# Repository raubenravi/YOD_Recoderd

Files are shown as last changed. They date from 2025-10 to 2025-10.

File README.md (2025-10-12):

# YOD Recorder - ESP32 Audio Recording System

ESP32-based audio recording system for research applications with QR code scanning and external hardware control.
This project contains the software developed for a graduation internship at the Hogeschool Utrecht research group artificial intelligence (lectoraat Ai).

# Developer Responsibility

** IMPORTANT NOTICE **

This system is designed for research and development purposes. **Before using this system in real-life applications, especially in medical or research environments, developers and users must:**

1. **Think Twice Before Implementation**: Carefully evaluate the appropriateness and safety of using this system in your specific use case
2. **Stakeholder Consultation**: Always discuss implementation plans with relevant stakeholders including:
   - Medical professionals (if used in healthcare)
   - Research supervisors and ethics committees
   - IT security teams
   - Legal and compliance departments
   - End users and participants
3. **Personal Responsibility**: The developer who is using it is solely responsible for:
   - Proper system validation and testing
   - Ensuring compliance with applicable regulations
   - Risk assessment and mitigation
   - Obtaining necessary approvals and certifications
   - Training users appropriately

**This code is provided as-is without warranty. Use at your own risk and responsibility.**

## What You Need

### Hardware
- **ESP32-WROOM-32D DevKit**
- USB cable
- SSD1306 OLED Display (128x64)
- DS3231 RTC Module
- M5Scanner (QR Code Scanner)
- Tascam DR-40X Digital Recorder
- 4x Push Buttons + 2x LEDs + Speaker

## Setup ESP-IDF

**Easiest way - VS Code Extension:**
1. Install [Visual Studio Code](https://code.visualstudio.com/)
2. Install [ESP-IDF Extension](https://marketplace.visualstudio.com/items?itemName=espressif.esp-idf-extension)
3. Follow setup wizard for ESP-IDF v5.0+

**Manual installation:**
- [Windows Setup Guide](https://docs.espressif.com/projects/esp-idf/en/latest/esp32/get-started/windows-setup.html)
- [macOS Setup Guide](https://docs.espressif.com/projects/esp-idf/en/latest/esp32/get-started/macos-setup.html)
- [Linux Setup Guide](https://docs.espressif.com/projects/esp-idf/en/latest/esp32/get-started/linux-macos-setup.html)

## Hardware Connections

Connect components to these ESP32 pins:

| Component | Pin | Notes |
|---|-----|---|
| **Display** | | |
| SSD1306 SCL | GPIO 21 | I2C Clock |
| SSD1306 SDA | GPIO 22 | I2C Data |
| **Buttons** | | |
| Research | GPIO 34 | |
| Select | GPIO 35 | |
| Stop | GPIO 32 | |
| Patient | GPIO 4 | External case |
| **Audio** | | |
| Modem | GPIO 25 | PWM Output |
| Speaker | GPIO 27 | PWM Output |
| **LEDs** | | |
| Status LED 1 | GPIO 2 | External case |
| Status LED 2 | GPIO 15 | External case |
| **Tascam** | | |
| RX | GPIO 16 | UART |
| TX | GPIO 17 | UART |

## Quick Start

### 1. Get the Code
```bash
git clone https://github.com/raubenravi/YOD_Recoderd
cd "YOD Recoder"
```

### 2. Setup Environment
**Windows PowerShell:**
```powershell
export IDF_PATH=~/esp/esp-idf
```

**Windows Command Prompt:**
```cmd
%IDF_PATH%\export.bat
```

### 3. Build and Flash
```bash
idf.py set-target esp32
idf.py build
idf.py -p COM3 flash
```
*Replace COM3 with your ESP32's port*

### 4. View Logs (Optional)
```bash
idf.py -p COM3 monitor
```

## How It Works

### Controls
- **Green Research Button**: Start research recording
- **Yellow Research Button**: pauze recording  
- **Red Research Button**: Stop all recording
- **Patient Button**: Patient pause (external case)

### Features
- Real-time display on OLED screen
- Audio analysis
- add marks with modem communication
- QR code scanning for participant ID
- Controls Tascam DR-40X recorder 
- Status LEDs and audio feedback

## Project Structure
```
YOD Recoder/
├── code_esp32/main/    # Main application code
├── components/         # Custom components  
├── test_code/               # Unit and integration tests
└── build/             # Generated files

```

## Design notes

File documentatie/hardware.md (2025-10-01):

# YOD Recorder Hardware Pin Configuration

This document describes the GPIO pin assignments and hardware connections for the YOD Recorder ESP32 project.

## GPIO Pin Assignment Table

| GPIO Pin | Hardware Component | Function | Direction | Notes |
|---|---|---|---|---|
| GPIO_2 | LED Controller | Status LED | Output | Controlled by GpioController, External case via cable |
| GPIO_4 | Button | Patient Button | Input | Pull-up enabled, Negative edge interrupt, External case via cable |
| GPIO_12  | Display | Reset Pin | Output | SSD1306 OLED Display Reset |
| GPIO_15  | LED Controller | Status LED | Output | Controlled by GpioController, External case via cable |
| GPIO_16  | UART2 | RX Pin | Input | Tascam DR-40X Communication (Inverted) |
| GPIO_17  | UART2 | TX Pin | Output | Tascam DR-40X Communication (Inverted) |
| GPIO_21  | I2C | SCL (Clock) | I/O | Display & RTC Communication |
| GPIO_22  | I2C | SDA (Data) | I/O | Display & RTC Communication |
| GPIO_25  | Audio Modem | PWM Output | Output | Audio FSK Modem (23kHz/21kHz) |
| GPIO_27  | Speaker | PWM Output | Output | Beeper/Speaker Control |
| GPIO_32  | Button | Stop Button | Input | Pull-up enabled, Positive edge interrupt |
| GPIO_34  | Button | Research Button | Input | Pull-up enabled, Positive edge interrupt |
| GPIO_35  | Button | Select Button | Input | Pull-up enabled, Positive edge interrupt |

## Hardware Components Details

### Display System
- **Component**: SSD1306 OLED Display (128x64)
- **Interface**: I2C
- **Pins**: 
  - SCL: GPIO_21
  - SDA: GPIO_22
- **Address**: Default I2C address (typically 0x3C)

### Real-Time Clock (RTC)
- **Component**: DS3231 RTC Module
- **Interface**: I2C (shared with display)
- **Pins**:
  - SCL: GPIO_21
  - SDA: GPIO_22

### QR Code Scanner
- **Component**: M5Scanner
- **Interface**: I2C (shared with display and RTC)
- **Pins**:
  - SCL: GPIO_21
  - SDA: GPIO_22

### Button Interface
All buttons are configured with:
- Internal pull-up resistors enabled
- Pull-down resistors disabled
- Individual interrupt handlers

| Button | GPIO | Interrupt Type | Observer ID |
|---|---|---|---|
| Research/Pause | GPIO_34 | Positive Edge | ResearchPause |
| Select/Start | GPIO_35 | Positive Edge | Start |
| Stop | GPIO_32 | Positive Edge | Stop |
| Patient/Pause | GPIO_4 | Negative Edge | PatientPause (External case via cable) |

### Audio System
#### Audio Modem
- **GPIO**: GPIO_25
- **Function**: FSK (Frequency Shift Keying) Modem
- **Frequencies**: 
  - High: 23,000 Hz
  - Low: 21,000 Hz
- **Implementation**: PWM-based signal generation

#### Speaker/Beeper
- **GPIO**: GPIO_27
- **Function**: Audio feedback and notifications
- **Implementation**: PWM-based tone generation

### Communication Interfaces
#### UART2 - Tascam DR-40X Control
- **Port**: UART_NUM_2
- **TX Pin**: GPIO_17
- **RX Pin**: GPIO_16
- **Configuration**:
  - Baud Rate: 9600
  - Data Bits: 8
  - Parity: Even
  - Stop Bits: 2
  - Flow Control: Disabled
  - Signal Inversion: Both TX and RX inverted

#### I2C Bus
- **Port**: I2C_NUM_0
- **SCL**: GPIO_21
- **SDA**: GPIO_22
- **Devices**: SSD1306 Display, DS3231 RTC, M5Scanner
- **Speed**: Standard 100kHz

### LED Status Indicators
- **GPIO_2**: Status LED (controlled by GpioController) - External case via cable
- **GPIO_15**: Status LED (controlled by GpioController) - External case via cable
- **Function**: Visual status indication for system states
- **Connection**: LEDs are mounted in external case and connected to ESP32 via cable

## Power and Ground Connections
- All components require 3.3V power supply
- Common ground connections for all components
- ESP32 DevKit provides regulated 3.3V output

## Pin Usage Summary
- **Total GPIO pins used**: 12 out of available ESP32 pins
- **Input pins**: 4 (buttons)
- **Output pins**: 6 (LEDs, PWM, Reset)
- **I/O pins**: 2 (I2C)
- **Communication pins**: 2 (UART)

## External Case Connections
Some components are mounted in an external case and connected to the main ESP32 board via cable:

- **Patient Button (GPIO_4)**: External momentary push button in case, connected via cable
- **Status LEDs (GPIO_2, GPIO_15)**: External indicator LEDs in case, connected via cable
- **Power (3.3V) and Ground**: The external case provides connections for 3.3V power and ground to supply the button.

## Notes
- All GPIO pins are configured with appropriate pull-up/pull-down resistors
- PWM channels use LEDC peripheral for audio generation
- UART signals are inverted for Tascam compatibility
- I2C bus is shared among multiple devices with different addresses
- Button debouncing is handled in software with interrupt-driven detection
- External case connections require proper cable management and strain relief

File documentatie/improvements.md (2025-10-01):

De volgende punten moeten bijgewerkt worden:
- Een RGB LED zodat elke gewenste kleur kan worden getoond
- De spraak-stilte ratio moet een hogere resolutie krijgen of fijner afgesteld kunnen worden zodat het beter is in het detecteren van stiltes
- Een standaard met formaat 5/8-27 threaded hole op de cases zodat verschillende richt- en shotgun microfoons aan het systeem bevestigd kunnen worden
- Betere uitlijning van de knoppen op de case voor de onderzoekers

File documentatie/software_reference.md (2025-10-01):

# Reference Manual
This manual is for software developers who want to understand the structure of the code. To read it properly, use a reader that supports Markdown.
# Task Handling

After all objects are constructed, the `startTasks()` function from the Task handler is called.

The TaskHandler controls all tasks using the ESP-IDF FreeRTOS framework.

There are two tasks running on the ESP: one task is responsible for general control of the system and its peripherals (`observerUpdateTask`).

## Observer Update Task
The `observerUpdateTask()` has 4 observers and one listener.
When the update function runs, the observers are stored in a vector because it's easier for development, but should be transferred to an array when memory becomes an issue or when it goes to production. When a new implementation of the observer is made, a new ID should be added to `ObserverIds`.

The observers are checked every 200 ms.

# Audio Analyser Task
The second task that is running is a task to count the silence-to-speaking ratio.
Every 250 ms, the audio analyser measures whether the speaker is silent or speaking.

# Observer-Listener Pattern

An example of how to make a new Observer:

```
//found in Observer.hpp
enum class ObserverIds {

    Start,

    Stop,

    PatientPause,

    ResearchPause,

    CodeScanner,

    AudioDataAvailable

/* add new id here */

};

class MyObserver: public Observer {

  ObserverId id;

  void update(){

  if() // Here should be the logic to check if Observer measured an event
  {
    listener->notify(id);
 }
};

};

```
There are two listeners: the menu controller and display controller.

# Button Handling

The buttons in the YOD recorder are polled with interrupt pins and integrated with the listener pattern. When a button is pressed, a flag will be set by the interrupt. When the `update()` function is called, the flag will be read and if necessary, it will call the `menuController.notify()` to update its state. 

# Menu Controller
The `MenuController` class contains most of the business logic. It contains an enum with the state of the recorder. The state can be changed by calling `notify()`. After `notify()` is called, the `menuTask` is called to update the state machine.

The `startRecording()` function is responsible for ensuring that the audio modem has the right data and that the right `TascamBoundary` is called.

The Tascam recorder used in the project (Tascam DR-40X) can be controlled with UART (see hardware documentation for how to connect it).
The Tascam has 3 states: stop, idle, and recording.
The `TascamBoundary` class can control and set the recorder to any of the 3 states independently of the current state, because it doesn't keep track of the state. This means that if one transition goes wrong, it doesn't affect the next transition.

## Tascam Control
The `TascamBoundary` class is responsible for sending the right data via UART to the Tascam recorder.

The `uart_set_line_inverse` is called because on the ESP32 it's already inverted. The UART signal should be high on 1, low on 0.
| Tascam command | Uart value |
|--|--|
| Start | 107 |
| Stop | 104 |

## UART Settings:

| Setting | Value |
|--|--|
| Rx pin | 16 |
| Tx pin | 17  |
| Baud rate | 9600 |
| Data bits | 8 |
| Parity | Even |

# PWM Channel

The `PWMChannel` class provides a thread-safe interface for controlling PWM (Pulse Width Modulation) signals using the ESP32's LEDC (LED Control) peripheral. This base class is designed to be inherited by other components that need PWM functionality.

## Key Features:
- Thread-safe operations using FreeRTOS mutexes
- Configurable frequency, duty cycle, and resolution
- Uses ESP32's LEDC peripheral for precise PWM control
- Default configuration: 10kHz frequency, 5-bit resolution
- Shared mutex across all PWM instances for safe multi-threaded access

The PWM channel is automatically paused after initialization and must be explicitly resumed by derived classes when needed.

# Speaker

The `Speaker` class extends `PWMChannel` to provide audio feedback functionality. It generates beep sounds at specified frequencies through a connected speaker.

## Functionality:
- Inherits thread-safe PWM control from `PWMChannel`
- `beep(frequency)` method for generating audio tones
- Used for user interface feedback and system notifications
- Configurable frequency for different beep tones

The speaker is typically used to provide audio confirmation when buttons are pressed or when system events occur.

# Audio Modem

The `AudioModem` class extends `PWMChannel` to implement Frequency Shift Keying (FSK) modulation for data transmission over audio channels. This enables the YOD recorder to transmit digital data as audio signals.

## Key Features:
- FSK modulation using two frequencies (high and low)
- Transmits 8-bit data values bit by bit
- Each bit is transmitted for 20ms duration
- Thread-safe transmission using mutex protection
- Automatically pauses PWM after transmission

## Operation:
1. Takes a mutex lock to ensure exclusive access
2. Resumes PWM signal generation
3. For each bit in the 8-bit data:
   - Sets high frequency for bit '1'
   - Sets low frequency for bit '0'
   - Waits 20ms before next bit
4. Pauses PWM signal after transmission
5. Releases mutex lock

This component is essential for encoding patient and research data into audio signals that can be recorded by the Tascam recorder and later decoded for analysis.

## Audio Modem Transmission Protocol

The audio modem transmits data as a structured packet with the following byte sequence:

| Byte Position | Data Type | Description | Value/Range | Notes |
|---|---|---|---|---|
| 1 | Sync | Synchronization byte 1 | 1 | Fixed sync pattern |
| 2 | Sync | Synchronization byte 2 | 2 | Fixed sync pattern |
| 3 | Sync | Synchronization byte 3 | 3 | Fixed sync pattern |
| 4 | Session ID | Current session identifier | 0-255 (uint64_t truncated) | Incremented for each new session |
| 5 | Time | Current minute | 0-59 | From RTC tm_min |
| 6 | Time | Current hour | 0-23 | From RTC tm_hour |
| 7 | Time | Day of month | 1-31 | From RTC tm_mday |
| 8 | Time | Month | 0-11 | From RTC tm_mon (0=Jan, 11=Dec) |
| 9 | Time | Year | Year offset | From RTC tm_year (years since 1900) |
| 10 | Flag | Patient number indicator | 1 or 2 | 1=patient number follows, 2=no patient number |
| 11* | Patient | First patient number digit | 0-9 | Only if flag=1 |
| 12* | Patient | Second patient number digit | 0-9 | Only if flag=1 |
| Last | Terminator | End marker | 3 | Fixed termination byte |

**Protocol Notes:**
- Bytes marked with * are conditional based on whether a patient number was scanned
- The session ID is transmitted as a single byte (truncated from uint64_t)
- Time values follow standard C `tm` structure format
- The protocol uses byte values 1, 2, 3 for synchronization and termination
- Total packet length: 10 bytes (no patient) or 12 bytes (with patient)
- Each byte is transmitted using FSK modulation with 20ms per bit (160ms per byte)

This protocol allows the receiver to synchronize with the transmission, extract session metadata, timestamp information, and optionally patient identification data.

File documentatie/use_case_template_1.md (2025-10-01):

# Uitwerking Use Case: Gesprek Opnemen (Sessie)

## 1. Doel van de use case

Het doel van deze use case is om het proces te beschrijven waarmee een onderzoeker een sessie (opname van een gesprek) start, pauzeert, hervat en beëindigt, waarbij ook de spraak-stilte-ratio wordt weergegeven. De sessie is gekoppeld aan één afspraak en wordt onder één uniek sessie-ID opgeslagen.

---

## 2. Actors

- **Onderzoeker:** Start, pauzeert, hervat en beëindigt de opname, en scant de patiëntenpas.
- **Spreker:** Kan de opname pauzeren via de blauwe knop.
- **Systeem:** Registreert, bewaart en verwerkt audio, toont status en spraak-stilte-ratio.

---

## 3. Precondities

- Er is een afspraak aanwezig tussen onderzoeker en spreker.
- De apparatuur is aangesloten en functioneert.
- De patiëntenpas is aanwezig.

---

## 4. Trigger

- Onderzoeker drukt op de groene knop óf scant de patiëntenpas.

---

## 5. Stroom (Hoofdsucces scenario)

1. **De onderzoeker scant de patiëntenpas** via het bedieningspaneel.
2. Het systeem koppelt de sessie aan de afspraak en genereert een uniek sessie-ID.
3. De onderzoeker drukt op de groene knop om de sessie te starten.  
   - Het systeem toont "idle" op het scherm; de opname staat standaard op pauze.
4. **Opname starten:** De onderzoeker drukt nogmaals op de groene knop.  
   - Het systeem geeft een pieptoon en schakelt de indicatorlampen aan.
   - De opname start; de spraak-stilte-ratio verschijnt op het scherm.
5. **Opname pauzeren:**  
   - De onderzoeker kan tijdens het opnemen op de gele knop drukken om te pauzeren.
   - De spreker kan op de blauwe knop drukken om te pauzeren.
   - Systeem toont "idle", opname stopt tijdelijk.
6. **Opname hervatten:**  
   - Alleen de onderzoeker kan op de groene knop drukken om te hervatten.
   - Pieptoon klinkt, indicatorlampen gaan aan, opname gaat verder.
7. **Opname beëindigen:**  
   - Onderzoeker drukt op de rode knop om de sessie te stoppen.
   - De opname wordt veilig opgeslagen onder het sessie-ID.

---

## 6. Alternatieve stromen

- **Spreker pauzeert opname:**  
  Spreker drukt op de blauwe knop, opname wordt gepauzeerd. Alleen de onderzoeker kan hervatten.
- **Onderzoeker pauzeert opname:**  
  Onderzoeker drukt op de gele knop, opname wordt gepauzeerd. Alleen de onderzoeker kan hervatten.

---

## 7. Systeemgedrag

- **Spraak-stilte-ratio:**  
  Elke 250 ms wordt in het frequentiegebied 300-3400 Hz gemeten of het signaal >5dB is.  
  - 2x achter elkaar signaal = spraak
  - Dit wordt 240 keer gemeten en als percentage weergegeven.
- **Audiovisuele weergave:**  
  Status ("idle", "record...") wordt getoond; lampjes en pieptoon geven status aan.
- **Beveiliging:**  
  Opnames kunnen alleen door de onderzoeker worden hervat na pauze.

---

## 8. Postcondities

- De sessie is opgeslagen met alle relevante metadata (sessie-ID, tijdstippen, spraak-stilte-ratio).
- De opname kan later worden teruggehaald of geanalyseerd.

---

## 9. Use Case diagram toelichting

Zie afbeelding (Image 1).  
- Actoren: onderzoeker, spreker.
- Hoofdusecase: gesprek opnemen.
- Extends: opnemen beëindigen, opnemen pauzeren.
- Includes: audiovisuele weergave, spraak/stilte ratio weergeven.
- Onderzoeker kan de patiëntpas scannen.

---

## 10. Notities

- Alleen de onderzoeker kan een sessie hervatten of stoppen.
- Spreker kan alleen pauzeren.
- De sessie blijft actief tot deze expliciet wordt beëindigd.

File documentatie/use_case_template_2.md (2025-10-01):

# Uitwerking Use Case: Gesprekken uitlezen met laptop (onderzoeker)

## 1. Doel van de use case

Het doel van deze use case is om het proces te beschrijven waarmee een onderzoeker de opnames van gesprekken van de recorder (bijvoorbeeld Tascam) kan uitlezen op zijn laptop, door de recorder via USB te verbinden. De onderzoeker kan vervolgens een overzicht krijgen van alle gesprekken, met tijd, datum en patiëntcode, en gesprekken openen in Audacity voor analyse van o.a. geluidsintensiteit.

---

## 2. Actoren

- **Onderzoeker:** Verbindt recorder met laptop, leest gesprekken uit, bekijkt overzichten, opent gesprekken in Audacity.
- **Systeem (laptop + uitleesprogramma):** Herkent recorder, toont overzicht, koppelt metadata, start Audacity.

---

## 3. Precondities

- Recorder bevat opgenomen gesprekken.
- Laptop beschikt over het uitleesprogramma en Audacity.
- USB-verbinding tussen recorder en laptop is mogelijk.

---

## 4. Trigger

- Onderzoeker sluit de recorder via USB aan op de laptop en start het uitleesprogramma.

---

## 5. Stroom (Hoofdsucces scenario)

1. **Recorder aansluiten:**  
   De onderzoeker verbindt de recorder via USB met de laptop.
2. **Uitleesprogramma starten:**  
   De onderzoeker start het uitleesprogramma op de laptop.
3. **Gesprekken laden:**  
   Het programma herkent de recorder en toont een overzicht van alle beschikbare gesprekken (bestanden).
4. **Overzicht tonen:**  
   Het overzicht bevat:
   - Tijd en datum van elk gesprek
   - Patiëntcode (indien beschikbaar)
5. **Gesprek selecteren:**  
   De onderzoeker selecteert een gesprek uit de lijst.
6. **Gesprek openen in Audacity:**  
   Het geselecteerde gesprek wordt geopend in Audacity voor verdere analyse/beluistering.
7. **Geluidsintensiteit bekijken:**  
   In Audacity kan de onderzoeker desgewenst de geluidsintensiteit visualiseren of analyseren.

---

## 6. Alternatieve stromen

- **Recorder niet herkend:**  
  Het programma geeft een foutmelding en vraagt om te controleren of de recorder correct is aangesloten.
- **Geen gesprekken gevonden:**  
  Het programma meldt dat er geen bestanden beschikbaar zijn.

---

## 7. Systeemgedrag

- **Automatische herkenning:**  
  Zodra de recorder via USB wordt aangesloten, zoekt het programma automatisch naar gespreksbestanden.
- **Metadata extractie:**  
  Het programma leest tijd/datum en patiëntcode uit de bestandsmetadata of bijbehorend logbestand.
- **Integratie met Audacity:**  
  Bij selectie van een bestand wordt Audacity automatisch gestart met het juiste gesprek.

---

## 8. Postcondities

- Onderzoeker heeft toegang tot alle opgenomen gesprekken en bijbehorende metadata op laptop.
- Gesprekken kunnen in Audacity worden beluisterd en geanalyseerd.

---

## 9. Use Case diagram toelichting

Zie afbeelding (Image 2).
- Actor: onderzoeker.
- Hoofdusecase: overzicht van alle gesprekken op de Tascam.
- Includes: overzicht tijd en datum, overzicht patiëntcode.
- Onderzoeker kan een gesprek openen in Audacity (waar mogelijk geluidsintensiteit wordt weergegeven).

---

## 10. Notities

- Overzicht is alleen beschikbaar als de recorder via USB is verbonden.
- Patiëntcode wordt alleen getoond indien aanwezig in het bestand/log.
- Audacity dient op de laptop geïnstalleerd te zijn voor volledige functionaliteit.

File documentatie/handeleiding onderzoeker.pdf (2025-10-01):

Aansluitingen
(Mini) Aux
Er zijn twee AUX-uitgangen: een mini-AUX en een standaard AUX. De mini-AUX is te herkennen aan de kleinere diameter van de connector.
XLR-kabel
De XLR-plug van de splitter met de enkele zijde moet in de Tascam-recorder worden aangesloten. De overige plugs worden aangesloten op de XLR-ingangen van de Tascam en de bedieningsdoos.

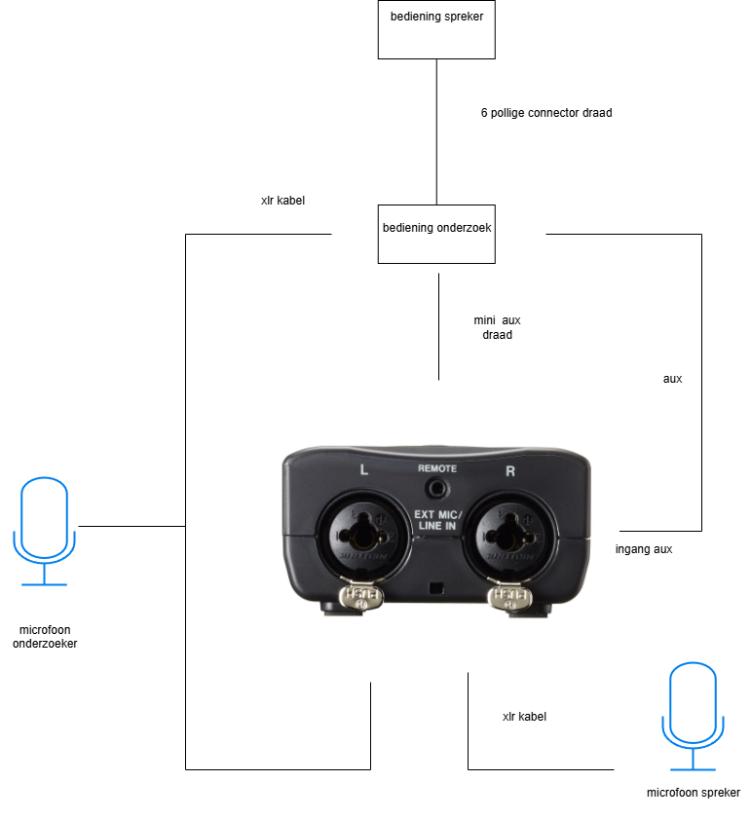
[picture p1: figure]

Aansluitschema

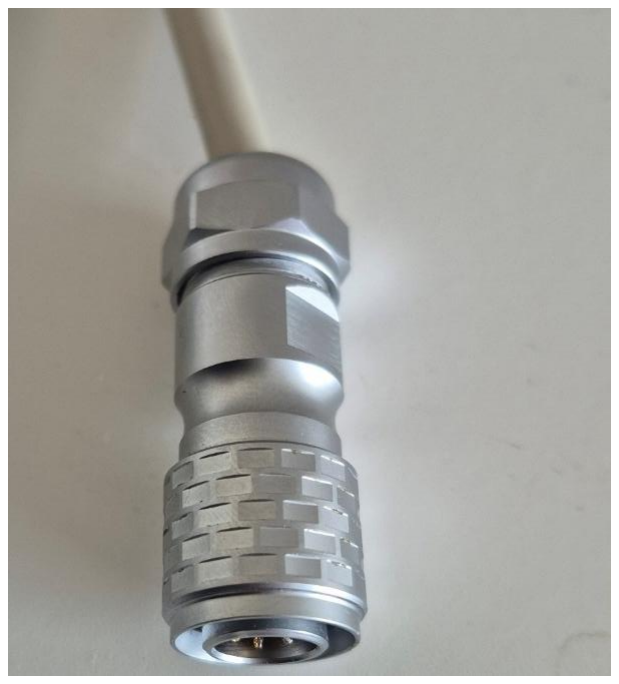
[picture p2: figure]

6 pollige connector om bedieningspanelen met elkaar te verbinden.

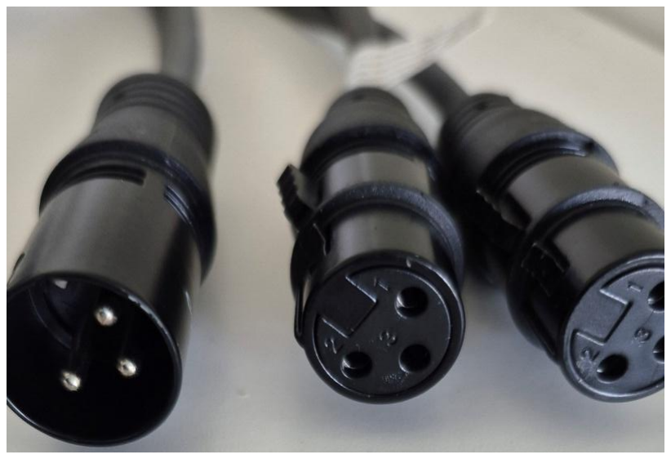
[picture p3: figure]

De xlr-splitter waarbij de rechter connector in de Tascam moet, van de andere twee moet éen verbonden worden met het bedieningspaneel van de onderzoeker en de andere met de microfoon van de onderzoeker.

Sessie
Een sessie is een gesprek bedoeld voor één spreker en gekoppeld aan één afspraak. Tijdens een sessie wordt het geluid opgenomen. De opname kan gepauzeerd en later hervat worden, dit blijft deel uitmaken van dezelfde sessie. Elke sessie krijgt een uniek sessie-ID.
Sessie starten
Een sessie kan gestart worden door op de groene knop te drukken of door een patiëntenpas te scannen. Na het starten staat de sessie standaard op pauze (op het scherm verschijnt “idle”).
- Om te beginnen met opnemen, moet opnieuw op de groene knop gedrukt worden. Op het scherm verschijnt dan “record..”.
- De sessie kan gestopt worden door op de rode knop te drukken.
- Tijdens het opnemen kan de sessie gepauzeerd worden door de onderzoeker met de gele knop of door de spreker met de blauwe knop.
- Alleen de onderzoeker kan een gepauzeerde sessie hervatten, door opnieuw de groene knop in te drukken.
Bij de start van een opname (of na hervatten) klinkt een pieptoon en gaan de indicatorlampen op het bedieningspaneel van de spreker branden.

Bedieningspanelen
Onderzoeker
Het bedieningspaneel van de onderzoeker heeft 4 knoppen:
- 3 knoppen voor het bedienen van de opname (groen, rood en geel)
- 1 knop voor het scannen van de patiëntenpas
Spreker
Het bedieningspaneel van de spreker heeft:
- een blauwe knop om de opname te pauzeren
- 2 rode LED-lampjes die aangeven dat er wordt opgenomen
- een ingebouwde speaker die een signaal geeft zodra de opname start. Deze speaker fungeert ook als referentiesignaal om de geluidsintensiteit te meten.

Spraak-stilte-ratio
Tijdens de opname wordt de spraak-stilte-ratio weergegeven. Elke 250 ms wordt gemeten als twee keer achter elkaar en er binnen frequentiegebied 300 en 3400 een signaal boven de 5 dB wordt gedetecteerd. In totaal wordt dit 240 keer gemeten. De resultaten worden weergegeven als percentage.

User interface laptopsoftware

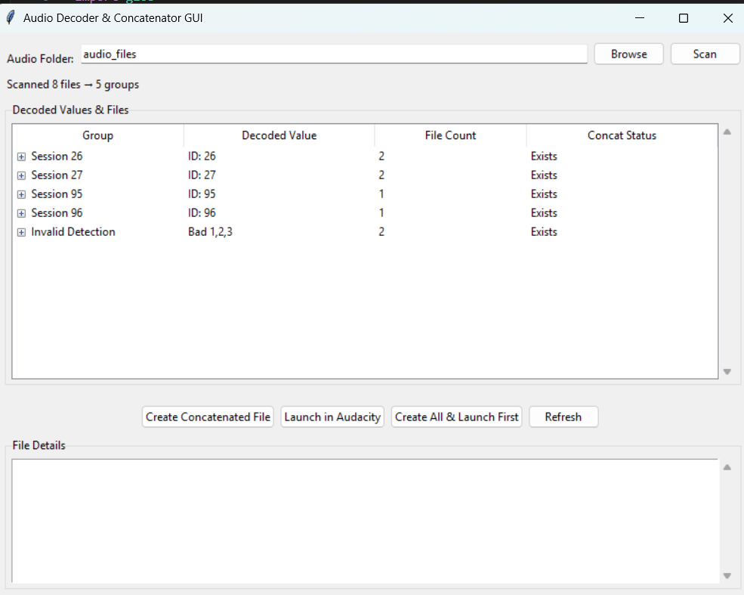
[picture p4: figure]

- Audio Folder:
Dit is de map die je selecteert – dit moet de muziekmap (music folder) van de Tascam zijn. Hier worden de audiobestanden gezocht.
- Decoded Value - Sessie ID:
In de kolom "Decoded Value" zie je bijvoorbeeld "ID: 26". Dit geeft het sessie-ID aan, oftewel: deze groep hoort bij sessie 26.
- Create Concatenated File:
Als je op deze knop klikt, wordt er van de geselecteerde groep een nieuw audiobestand gemaakt waarin alle bijbehorende bestanden achter elkaar geplakt zijn.
- Launch in Audacity:
Deze knop start Audacity en opent daarin het samengestelde audiobestand.
- Create All & Launch First:
Hiermee worden voor alle sessies audio-bestanden gemaakt én wordt het eerste bestand direct geopend in Audacity.

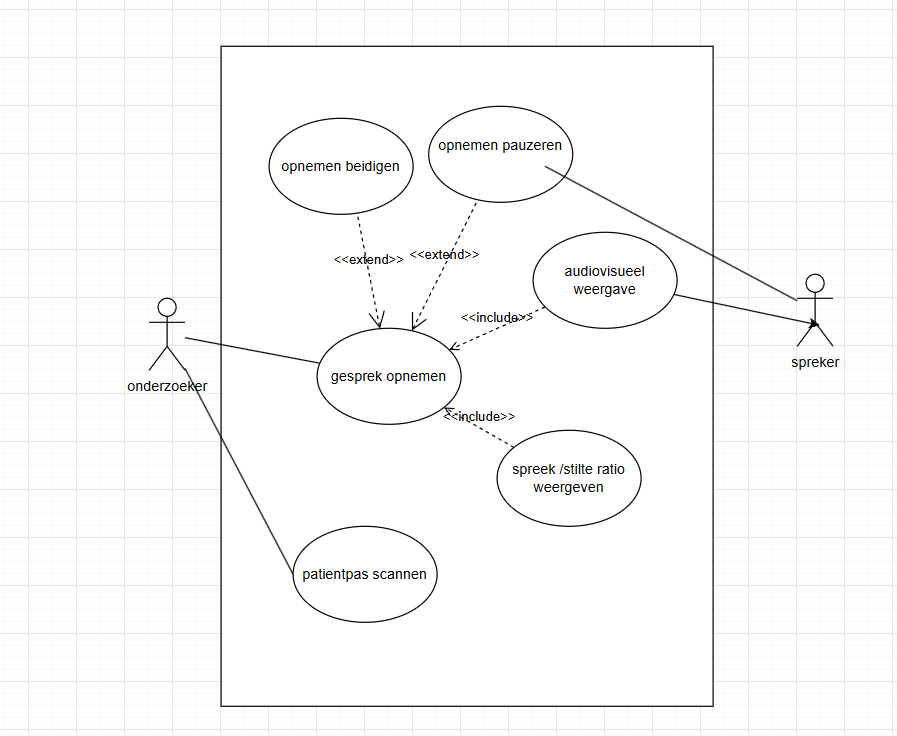
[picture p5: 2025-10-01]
documentatie/use_case_diagrame_1.png

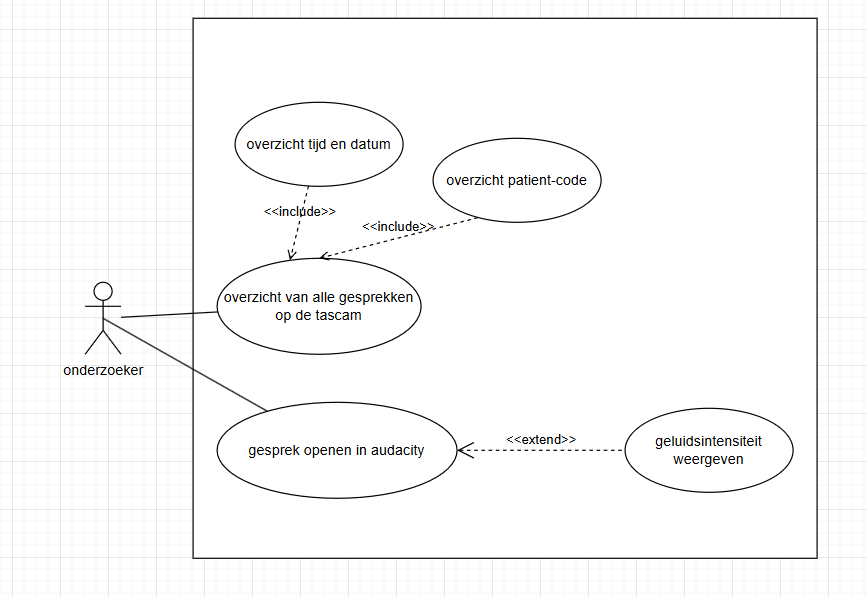
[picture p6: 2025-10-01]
documentatie/use_case_diagrame_2.png

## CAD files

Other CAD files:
3d_files/houder_recoder/houder_yod_recoder v1.f3d
3d_files/patient/base_robust v1.f3d
3d_files/patient/patient_side v1.f3d
3d_files/patient/rbust_top v1.f3d
3d_files/research_control/new_research_control v1.f3d
3d_files/research_control/robut_top_research v1.f3d
3d_files/research_control/side_research_control_with_holes v1.f3d

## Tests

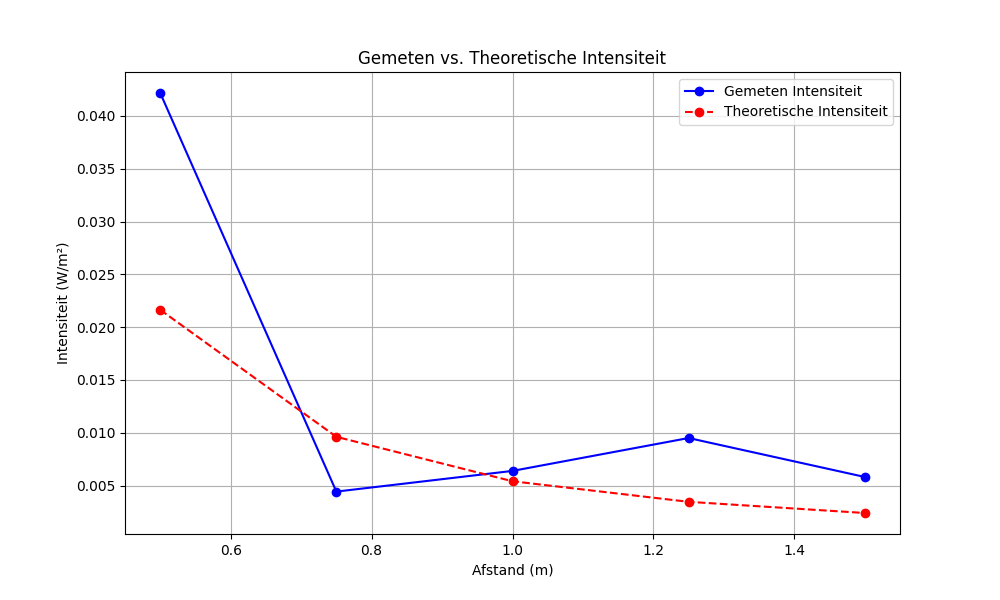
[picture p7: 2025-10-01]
test_code/Unit-test-geluidsintensiteit/intensity_plot.png

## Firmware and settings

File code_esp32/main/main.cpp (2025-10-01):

#include <stdio.h>
#include <memory>
#include "freertos/FreeRTOS.h"
#include "freertos/task.h"
#include "freertos/queue.h"
#include "esp_log.h"
#include "driver/gpio.h"
#include "audioModem.hpp"
#include "menuController.hpp"
#include "buttonBoundary.hpp"
#include "m5Scanner.hpp"
#include "tascamBoundary.hpp"
#include "audioAnalyzer.hpp"
#include "displayController.hpp"
#include "RealTimeClock.hpp"
#include "taskHandler.hpp"
#include "headers/WordCountQueueObserver.hpp"
#include "gpioController.hpp"
#include "headers/hardware_config.hpp"

extern "C" void app_main(void) {
    ESP_LOGI("YOD_RECORDER", "Starting initialization...");

    // GPIO Service and Controller
    gpio_install_isr_service(ESP_INTR_FLAG_IRAM);
    GpioController gpioController;
    gpioController.initialize();
    gpioController.setGpio2Level(0);

    // Buttons
    ButtonBoundary buttonResearch(BUTTON_RESEARCH_PIN, ObserverId::ResearchPause, GPIO_INTR_POSEDGE);
    ButtonBoundary buttonSelect(BUTTON_SELECT_PIN, ObserverId::Start, GPIO_INTR_POSEDGE);
    ButtonBoundary buttonStop(BUTTON_STOP_PIN, ObserverId::Stop, GPIO_INTR_POSEDGE);
    ButtonBoundary buttonPatient(BUTTON_PATIENT_PIN, ObserverId::PatientPause, GPIO_INTR_NEGEDGE);
    buttonResearch.initialize();
    buttonSelect.initialize();
    buttonStop.initialize();
    buttonPatient.initialize();

    // Queue
    QueueHandle_t countQueue = xQueueCreate(5, sizeof(uint8_t));

    // Display and RTC
    SSD1306_t display_dev;
    i2c_master_init(&display_dev, CONFIG_SDA_GPIO, CONFIG_SCL_GPIO, CONFIG_RESET_GPIO);
    auto display = std::make_unique<DisplayController>(&display_dev, countQueue);
    RealTimeClock rtcClock(display_dev._i2c_bus_handle);
    rtcClock.initialize();

    // Peripherals
    M5Scanner scanner(display_dev._i2c_bus_handle);
    scanner.initialize();
    AudioModem modem(23000, 21000, AUDIO_MODEM_PIN);
    modem.initialize();
    TascamBoundary tascamBoundary(TASCAM_UART_NUM, new QueueHandle_t);
    tascamBoundary.initialize();

    // Observer and Speaker
    WordCountQueueObserver wordCountQueueObserver(countQueue);
    Speaker speaker(SPEAKER_PIN);
    speaker.initialize();

    // Menu Controller
    NvsBoundary nvsBoundaryInstance;
    auto storage = std::make_unique<Storage>(nvsBoundaryInstance);
    auto menu = std::make_unique<MenuController>(
        display.get(), storage.get(), scanner, buttonSelect, buttonPatient, buttonStop,
        tascamBoundary, modem, nvsBoundaryInstance , countQueue, rtcClock, speaker, gpioController
    );

    // Set Listeners
    buttonSelect.setListener(*menu);
    buttonStop.setListener(*menu);
    buttonPatient.setListener(*menu);
    buttonResearch.setListener(*menu);
    wordCountQueueObserver.setListener(*display);

    // Start Tasks
    //TODO nog naar array veranderen
    std::vector<Observer*> observers = {&buttonPatient, &buttonSelect, &buttonStop, &buttonResearch, &wordCountQueueObserver}; 
    TaskHandler taskHandler(observers, countQueue, *menu);
    taskHandler.startTasks();

    ESP_LOGI("YOD_RECORDER", "Initialization complete. Starting main loop...");
    while (true) {
        vTaskDelay(portMAX_DELAY);
    }
}

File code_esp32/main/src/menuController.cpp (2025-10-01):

#include "menuController.hpp"
#include "esp_log.h"
#include <string.h>
#include <limits>

MenuController::MenuController(DisplayController *displayController, Storage *storage, M5Scanner &scanner, ButtonBoundary &selectButton, ButtonBoundary &startButton, ButtonBoundary &stopButton, TascamBoundary &tascamBoundary, AudioModem &audioModem, NvsBoundary &nvs, QueueHandle_t countQueue, RealTimeClock &rtc, Speaker &speaker, GpioController &gpioController)
    : currentState(State::LOGING),
      display(displayController),
      storage(storage),
      currentSelection(1),
      scanner(scanner),
      selectButton(selectButton),
      startButton(startButton),
      stopButton(stopButton),
      tascamBoundary(tascamBoundary),
      audioModem(audioModem),
      nvs(nvs),
      audioCountQueue(countQueue),
      rtc(rtc),
      speaker(speaker),
      gpioController(gpioController),
      inSession(false),
      numberScanned(false) {}

MenuController::~MenuController() {}

void MenuController::notify(ObserverId buttonId) {
    switch (buttonId) {
        case ObserverId::CodeScanner:
            patientNumber = scanner.getCode();
            display->displayText(1, (char*)patientNumber);
            numberScanned = true;
            [[fallthrough]];
        default:
            menuTask(buttonId);
            break;
    }
}

void MenuController::startRecording() {
    struct tm current_time;
    rtc.getTime(current_time);
    uint64_t sessionId = storage->getSessionId();

    if (!inSession) {
        sessionId = (sessionId < std::numeric_limits<uint64_t>::max()) ? sessionId + 1 : 0;
        storage->setSessionId(sessionId);
    }

    tascamBoundary.startRecording();
    // 1, 2, 3 are for syncing
    audioModem.transmit(1);
    audioModem.transmit(2);
    audioModem.transmit(3);
    //sesionId and time info sending
    audioModem.transmit(sessionId);
    audioModem.transmit(current_time.tm_min);
    audioModem.transmit(current_time.tm_hour);
    audioModem.transmit(current_time.tm_mday);
    audioModem.transmit(current_time.tm_mon);
    audioModem.transmit(current_time.tm_year);

    if (numberScanned && !inSession) {
        //to let the receiver know that patient number will be send
        audioModem.transmit(1);
        audioModem.transmit(patientNumber[0]);
        audioModem.transmit(patientNumber[1]);
        patientNumber = nullptr;
        numberScanned = false;
    } else {
        // Indicate no patient number is being sent
        audioModem.transmit(2);
    }
    //to let the receiver know that patient number will be send
    audioModem.transmit(3);
    inSession = true;
    speaker.beep(500);
    display->displayTextX3(2, "Rec...", false);
    vTaskDelay(pdMS_TO_TICKS(200));
}

void MenuController::menuTask(ObserverId buttonId) {
    switch (currentState) {
        case State::LOGING:
            if (scanner.checkIfCodeIsScanned()) {
                patientNumber = scanner.getCode();
                numberScanned = true;
                display->clear();
                display->displayText(2, "Patient number scanned");
                ESP_LOGI("SCANNER", "Patient number: %s", (char *)patientNumber);
                currentState = State::IDLE;
            }
            break;
        case State::IDLE:
            if (buttonId == ObserverId::Start) {
                startRecording();
                currentState = State::RECORDING;
            } else if (buttonId == ObserverId::Stop) {
                inSession = false;
                display->clear();
                display->displayText(2, "Log in patient");
                currentState = State::LOGING;
            }
            break;
        case State::RECORDING:
            if (buttonId == ObserverId::Stop) {
                tascamBoundary.stopRecording();
                display->clear();
                display->displayText(2, "Log in patient");
                currentState = State::LOGING;
                inSession = false;
                numberScanned = false;
                patientNumber = nullptr;
            } else if (buttonId == ObserverId::PatientPause) {
                gpioController.setLow();
            } else if (buttonId == ObserverId::ResearchPause) {
                gpioController.setHigh();
            }
            break;
    }
}

MenuController::State MenuController::getCurrentState() const {
    return currentState;
}

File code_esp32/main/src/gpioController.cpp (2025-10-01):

#include "gpioController.hpp"
#include "esp_log.h"

static const char *TAG = "GpioController";

GpioController::GpioController() 
    : gpio2(GPIO_NUM_2), gpio15(GPIO_NUM_15), initialized(false) {
}

GpioController::~GpioController() {
    // GPIO cleanup is handled by ESP-IDF when the program ends
}

esp_err_t GpioController::initialize() {
    if (initialized) {
        ESP_LOGW(TAG, "GPIO controller already initialized");
        return ESP_OK;
    }

    // Configure GPIO pins
    gpio_config_t io_conf = {};
    io_conf.intr_type = GPIO_INTR_DISABLE;
    io_conf.mode = GPIO_MODE_OUTPUT;
    io_conf.pin_bit_mask = (1ULL << gpio2) | (1ULL << gpio15);
    io_conf.pull_down_en = GPIO_PULLDOWN_DISABLE;
    io_conf.pull_up_en = GPIO_PULLUP_DISABLE;
    
    esp_err_t ret = gpio_config(&io_conf);
    if (ret != ESP_OK) {
        ESP_LOGE(TAG, "Failed to configure GPIO pins: %s", esp_err_to_name(ret));
        return ret;
    }

    // Set initial levels: GPIO 2 high, GPIO 15 low
    gpio_set_level(gpio2, 0);
    gpio_set_level(gpio15, 0);

    initialized = true;
    ESP_LOGI(TAG, "GPIO controller initialized successfully");
    return ESP_OK;
}

void GpioController::setHigh() {
    if (!initialized) {
        ESP_LOGE(TAG, "GPIO controller not initialized");
        return;
    }
    
    gpio_set_level(gpio2, 1);
    gpio_set_level(gpio15, 1);
    ESP_LOGD(TAG, "Set GPIO2=HIGH, GPIO15=LOW");
}

void GpioController::setLow() {
    if (!initialized) {
        ESP_LOGE(TAG, "GPIO controller not initialized");
        return;
    }
    
    gpio_set_level(gpio2, 0);
    gpio_set_level(gpio15, 0);
    ESP_LOGD(TAG, "Set GPIO2=LOW, GPIO15=HIGH");
}

void GpioController::setGpio2Level(int level) {
    if (!initialized) {
        ESP_LOGE(TAG, "GPIO controller not initialized");
        return;
    }
    
    gpio_set_level(gpio2, level);
    ESP_LOGD(TAG, "Set GPIO2=%d", level);
}

void GpioController::setGpio15Level(int level) {
    if (!initialized) {
        ESP_LOGE(TAG, "GPIO controller not initialized");
        return;
    }
    
    gpio_set_level(gpio15, level);
    ESP_LOGD(TAG, "Set GPIO15=%d", level);
}

int GpioController::getGpio2Level() {
    if (!initialized) {
        ESP_LOGE(TAG, "GPIO controller not initialized");
        return -1;
    }
    
    return gpio_get_level(gpio2);
}

int GpioController::getGpio15Level() {
    if (!initialized) {
        ESP_LOGE(TAG, "GPIO controller not initialized");
        return -1;
    }
    
    return gpio_get_level(gpio15);
}

bool GpioController::isInitialized() const {
    return initialized;
}
